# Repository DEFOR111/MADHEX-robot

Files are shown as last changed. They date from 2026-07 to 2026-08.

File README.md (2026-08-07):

# ***MADHEX — Open Source Hexapod Robot***
## 18 DOF · ESP32-S3 · Full custom PCB · CAD included
WhatsApp Image 2026-07-16 at 12 32 35 PM (1)

### ***A fully open-source hexapod project — PCB, CAD  included — for anyone who wants to build their own six-legged walking robot.***

***Features · PCB · CAD & Mechanics · Build Instructions · Gallery · Roadmap · Contributing***

-------------------------------------------------------------------------------------------------------------------------------------------------------------------------
## ***About:*** 
**MADHEX** is a fully open-source hexapod (six-legged) robot project. It includes a custom-designed power/control PCB, complete mechanical CAD files, and everything needed to build, wire, and bring your own hexapod to life — from soldering the board to your first steps in inverse kinematics.

**This repo is built for makers, robotics students, and hobbyists who want a real Hexapod .**

----------------------------------------------------------------------------------------------------------------------------------
## Features
	
* **18 DOF**	Full range of motion — walk, rotate in place, and climb
* **ESP32-S3-WROOM-1**	Onboard MCU handles inverse kinematics and gait control
* **Custom power PCB**	Compact board with dual buck converters, up to 600 W
* **BNO055 IMU**	Real-time orientation and stability feedback
* **32-channel PWM**	Room to expand with sensors, grippers, or accessories
* **All-terrain** capable	Stable gait tuned for uneven surfaces
* **Fully open**	PCB design, CAD, and build docs — all included

------------------------------------------------------------------------------------------------------------------------------------------------------------------
## PCB
PCB Top view

 ***The board is designed to be compact, efficient, and easy to assemble, while still driving 18 servos with headroom to spare.***

### Component	Spec
* Power stage	Dual buck converters, 40 A / up to 600 W combined — stable under peak servo load
* Servo power rails	2 independent lines (J5–J20 = rail A, J21–J36 = rail B) — 9 servos per rail for balanced current draw
* Current sensing	2× INA226 for real-time power monitoring
* PWM outputs	32 channels via 2× PCA9685
* MCU	ESP32-S3-WROOM-1 — inverse kinematics + gait control
* IMU	BNO055 — orientation, balance, stability
* Logic supply	AMS1117 3.3 V regulator
* I/O	USB-C, 2× SMD buttons

***Why it matters:*** **a small footprint board that reliably drives 32 PWM channels means more room in the chassis for batteries, sensors, or a gripper — without redesigning the electronics.**

Снимок экрана 2026-08-02 171105

### **DRC** - this PCB design includes only 2 warnings with 0 mistakes which means it is ready for manufactoring and these 2 warnings is just Kicad  and footprint problem of esp32-s3 footprint 

-------------------------------------------------------------------------------------------------------------------------------------------------------------------
## CAD 
WhatsApp Image 2026-07-16 at 12 32 35 PM (2)

| Spec | Value |
| :--- | :--- |
| **Size** | ~800 mm length × 300 mm height |
| **Servos** | DS3235 (high-torque, no secondary shaft) |
| **Shaft support** | Added bearings on each joint to compensate for the single-shaft servo design, reducing backlash and improving long-term stability |
| **Range of motion** | Mid-to-high performance angle range, tuned for smooth walking gait |

## building Instruction 

WhatsApp Image 2026-07-20 at 11 35 21 PM

* Print/order the chassis — CAD files in /cad
* Assemble the PCB — schematics and Gerbers in /pcb
* Wire the servos — respect the two power rails (9 servos per rail)

(FOR HACK CLUB: i have changed a bit of project in electronics to prevent it from braking after the submission )

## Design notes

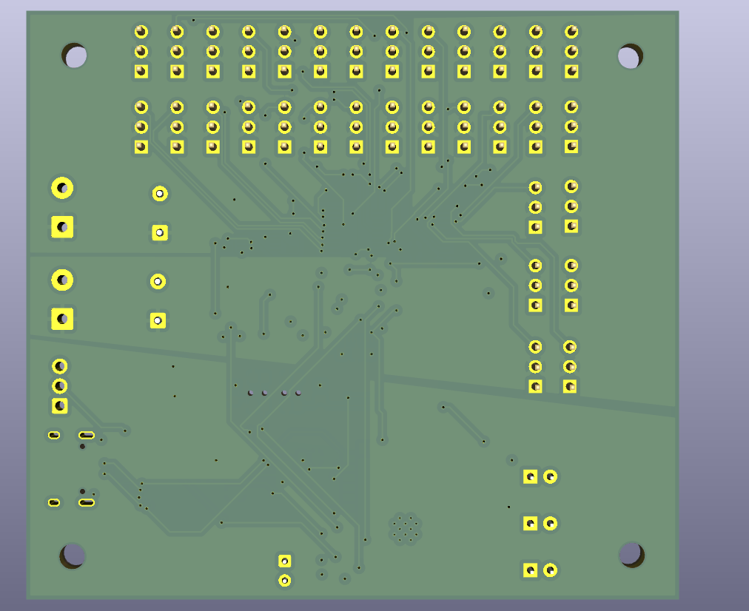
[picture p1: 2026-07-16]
Renders/PCB Bottom view.png

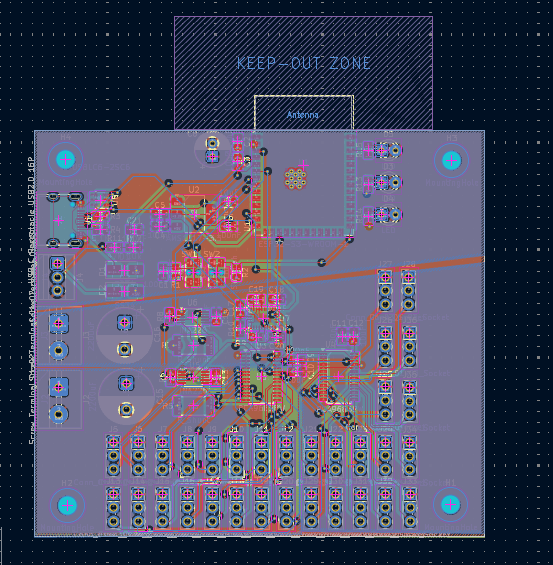
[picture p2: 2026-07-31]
Renders/4layer.png

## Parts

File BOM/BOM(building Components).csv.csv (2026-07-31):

name | quantity | price for quantity + delivery | link
DS3235 - 180 Servo | 18 | 246.78$ | https://aliexpress.ru/item/1005007575629790.html?sku_id=12000041358164109
servo horn | 2 | 11.13$ | https://aliexpress.ru/item/1005003027854823.html?sku_id=12000023318820499
3S Lipo battery 6000mAh | 1 | 45.34$ | https://aliexpress.ru/item/1005008702710375.html?sku_id=12000046311555698
300W 20A dc-dc step down buck converter | 2 | 9.14 | https://aliexpress.ru/item/1005004894829745.html?sku_id=12000030927228556
Esp32-s3-Wroom-1 module | 1 | 3.06$ | https://aliexpress.ru/item/1005010605134917.html?sku_id=12000052954553787
Usb-c 16 pin 0.8mm | 1 | 1.39$ | https://aliexpress.ru/item/1005007748645481.html?sku_id=12000042099025955
BNO055 IMU | 1 | 7.23$ | https://aliexpress.ru/item/1005008153313742.html?sku_id=12000044013847289
lm2596 step down buck converter | 1 | 0.77$ | https://aliexpress.ru/item/1005003780274326.html?sku_id=12000027142887130
Pca9685 | 1 | 4.36$ | https://aliexpress.ru/item/1005008013388973.html?sku_id=12000043251084556
diode s34 SMA | 1 | 1.5$ | https://aliexpress.ru/item/1005011924308998.html?sku_id=12000057043294917
LED lights | 1 | 0.89$ | https://aliexpress.ru/item/1005003483934428.html?sku_id=12000025994266348
INA226 | 2 | 1.39$ | https://aliexpress.ru/item/1005010486173276.html?sku_id=12000052565428459
16V2200uF Capacitor | pack | 1.1$ | https://aliexpress.ru/item/1005005698363806.html?sku_id=12000034044860759
16V100uF Capacitor | pack | 1.27$ | https://aliexpress.ru/item/1005005698363806.html?sku_id=12000034044860751
0805 smd 100nF Capacitor | pack | 1.05$ | https://aliexpress.ru/item/33010719216.html?sku_id=67141324253
0805 smd 10uF Capacitor |  | 1.19$ | https://aliexpress.ru/item/33010719216.html?sku_id=67141324254
Screw terminal 2.54mm 3PIN | 1 | 2.78$ | https://aliexpress.ru/item/1005007455322674.html?sku_id=12000040827977848
Screw terminal 5mm 2PIN | 2 | 2.25$ | https://aliexpress.ru/item/1005007455322674.html?sku_id=12000040827977861
male pin headers 1x40 | 1-2packs(we need 32 overall) | 2.10$ | https://aliexpress.ru/item/1005007067304088.html?sku_id=12000039296567404
0805 resistor 1k smd | pack | 1.07$ | https://aliexpress.ru/item/1005011924238866.html?sku_id=12000057033019725
0805 resistor 5.1k smd | pack | 1.07$ | https://aliexpress.ru/item/1005011924238866.html?sku_id=12000057033019742
0805 resistor 10k smd | pack | 1.07$ | https://aliexpress.ru/item/1005011924238866.html?sku_id=12000057033019749
0805 resistor 47k smd | pack | 1.07$ | https://aliexpress.ru/item/1005011924238866.html?sku_id=12000057033019765
R-Shunt 2512 3W-0.002 2mR | pack | 3.22$ | https://aliexpress.ru/item/1005012015238252.html?sku_id=12000057293682538
SMD 2Pin 3X4MM Tactile Tact Push Button Micro Switch | 2 | 1.5$ | https://aliexpress.ru/item/32752118872.html?sku_id=61896432967
ams1117 3.3v | 1 | 0.63$ | https://aliexpress.ru/item/1005008229056966.html?sku_id=12000048372042089
USBLC6-2SC6 SOT23-6 | 1 | 1.21$ | https://aliexpress.ru/item/1005009468432448.html?sku_id=12000049196393604
3D Printer Filament PETG 1.75mm 1kg/2.2lbs Plastic Filament Consumables PETG Material for 3D Printer | 1 | owned | https://aliexpress.ru/item/2042369676.html?sku_id=12000015581361162
688 series bearings | 2 | 3.68$ | https://aliexpress.ru/item/1005007514760760.html?sku_id=12000041090570973
M3 Inserts 3x5x4 | pack | 3.95$ | https://aliexpress.ru/item/1005009631947915.html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
M3 screws 12mm and 6mm | 2 packs of screws | 2.54$ | https://aliexpress.ru/item/1005002193355886.html?sku_id=12000019011281721
total price | 360.56$ + 16% VAT + delivery | 416.14$ for components

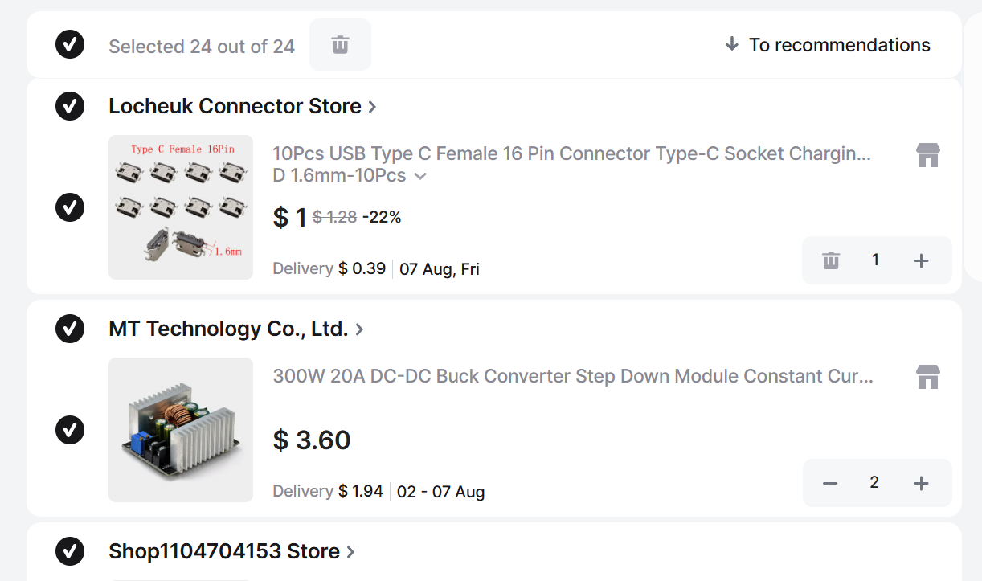
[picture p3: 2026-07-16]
BOM/cart aleiexpress 8.png

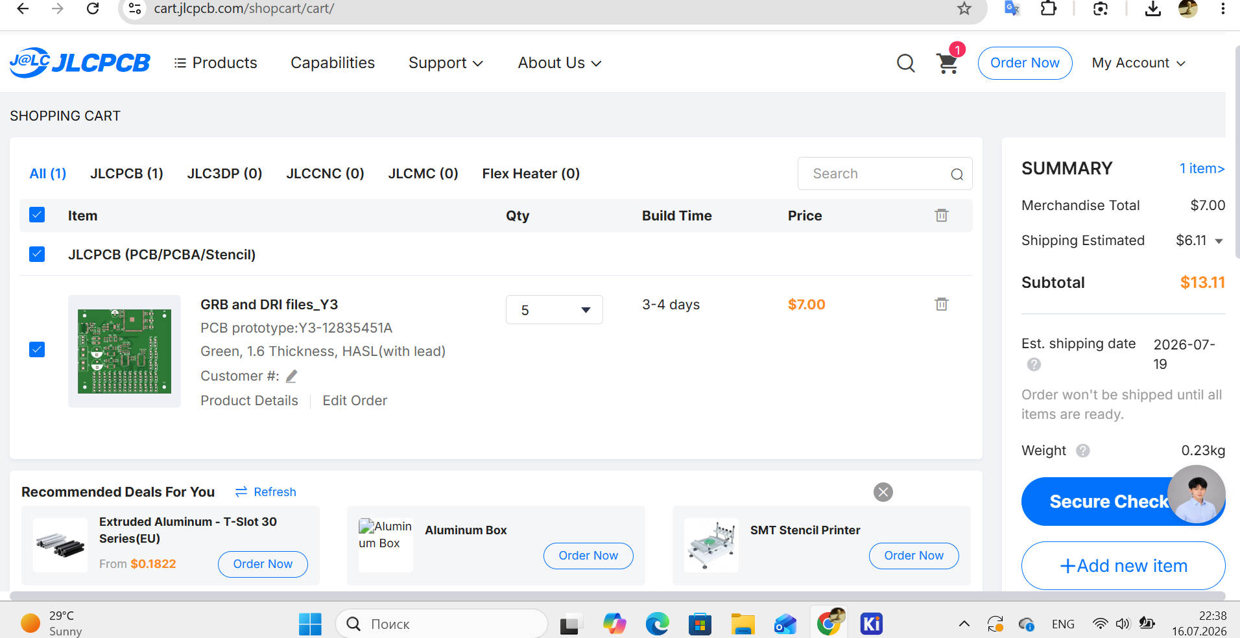
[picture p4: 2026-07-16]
BOM/JLCPCB cart hexapod.png

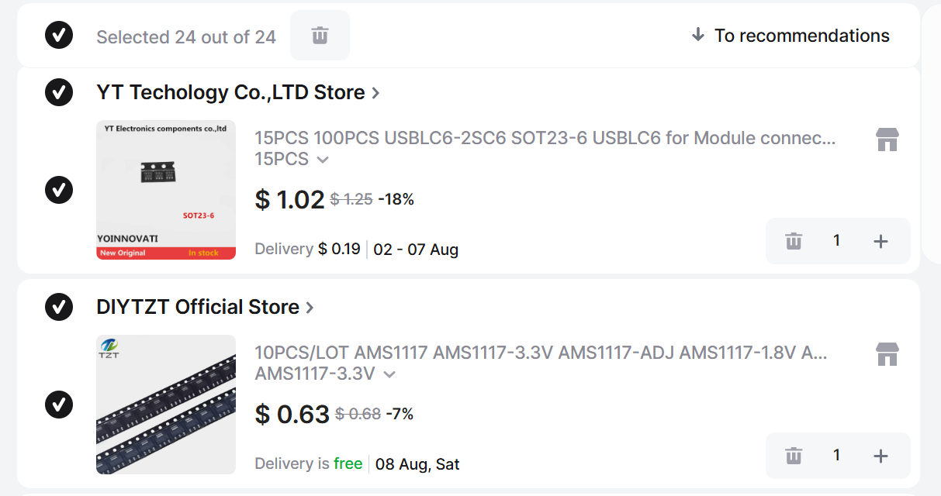
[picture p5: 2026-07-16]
BOM/cart aleiexpress 1.png

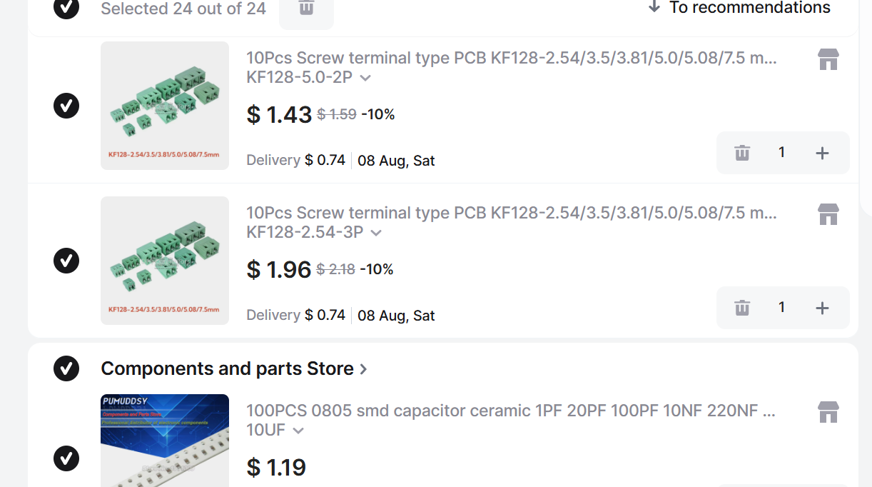
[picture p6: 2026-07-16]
BOM/cart aleiexpress 4.png

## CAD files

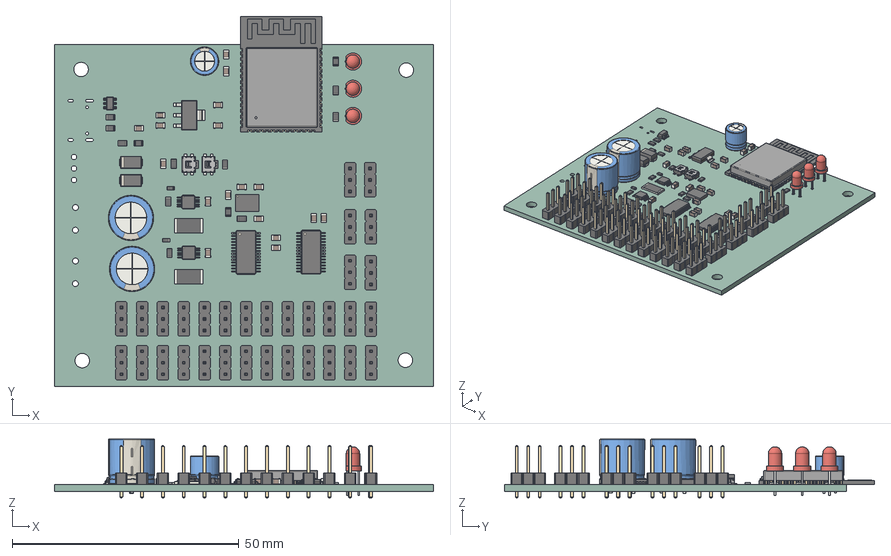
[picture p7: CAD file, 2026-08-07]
CAD/Hexapod PCB(CAD).step
83.6 x 81.6 x 13.0 mm
PinHeader_1x03_P254mm_Vertical x 32
C_0805_2012Metric x 18
R_0805_2012Metric x 13
R_2512_6332Metric x 2
D_SMA x 2
LED_D3.0mm x 3
CP_Radial_D100mm_P500mm x 2
R_0603_1608Metric x 2
ESP32-S3-WROOM-1
SOT-223
CP_Radial_D63mm_P250mm
SW_SPST_EVQP7C x 2
TSSOP-10_3x3mm_P0.5mm x 2
LGA_28_52x38mm_P05mm
TSSOP-28_4.4x9.7mm_P0.65mm x 2
SOT-23-6
HexF20F_PCB

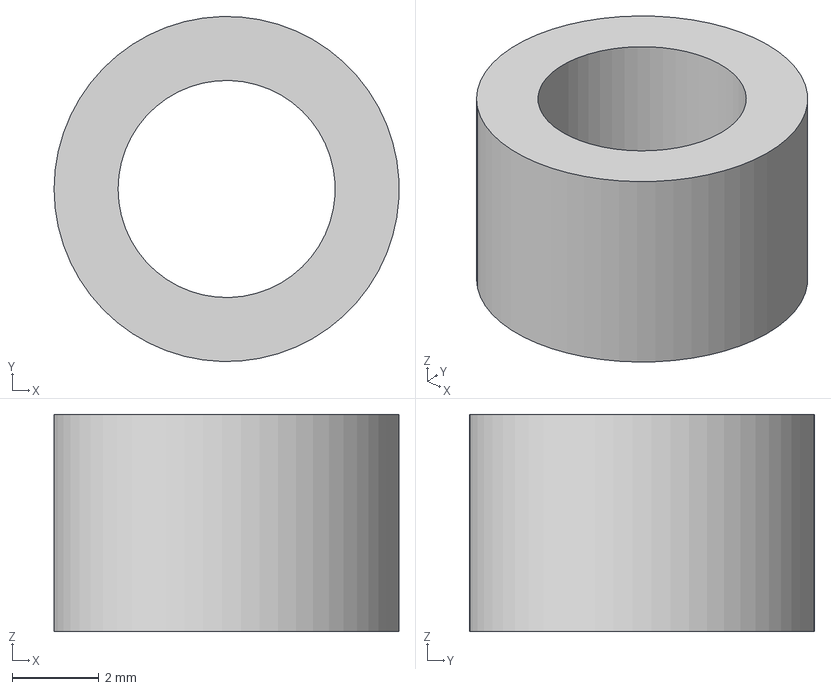
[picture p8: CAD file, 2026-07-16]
CAD/Step files/insert hold part.step
7.94 x 7.95 x 5.00 mm

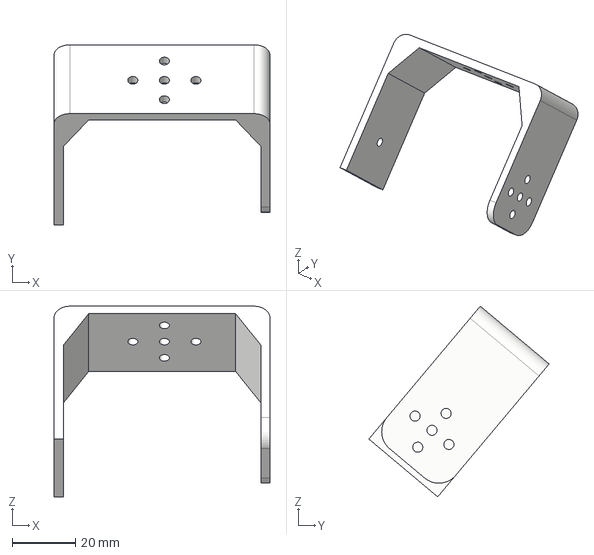
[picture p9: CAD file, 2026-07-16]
CAD/Step files/Femur mounting hub.step
68.5 x 57.2 x 60.5 mm

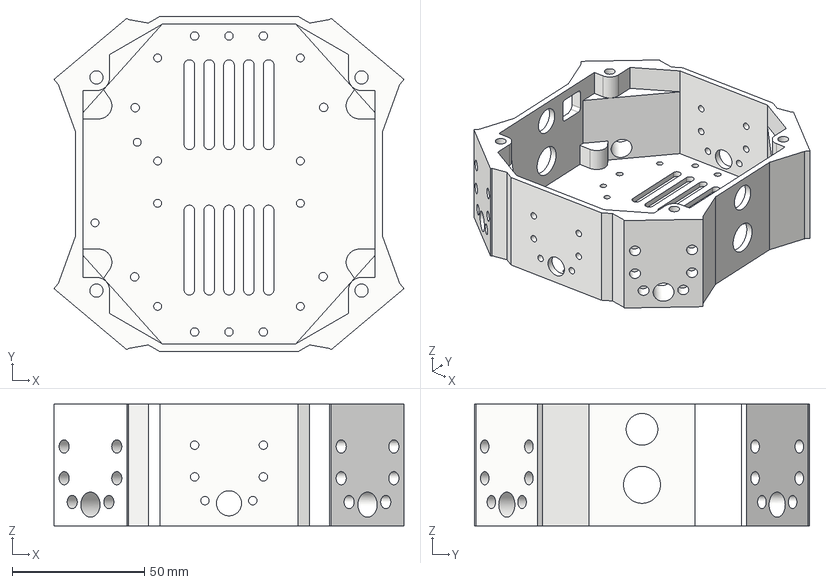
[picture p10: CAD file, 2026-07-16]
CAD/Step files/case.step
132.4 x 126.9 x 46.0 mm

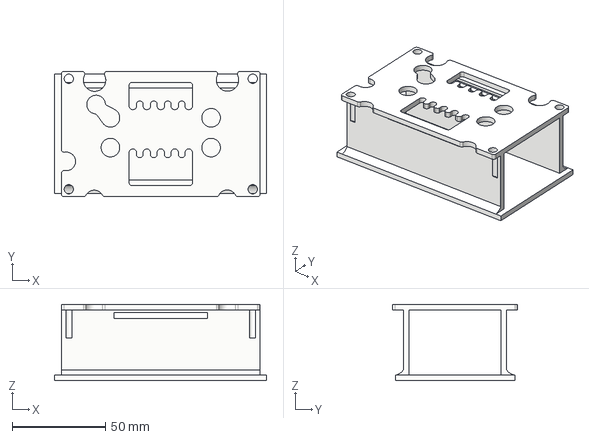
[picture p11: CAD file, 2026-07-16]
CAD/Step files/battery holder.step
113.7 x 67.2 x 41.0 mm

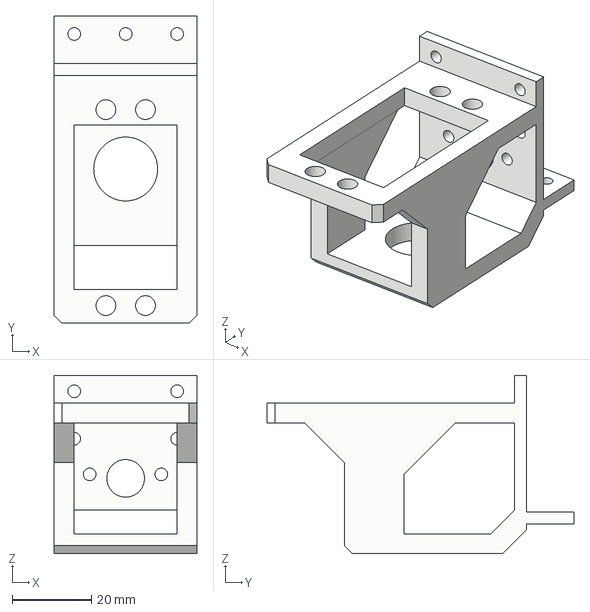
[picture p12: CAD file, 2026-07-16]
CAD/Step files/Coxa mounting hub.step
36.1 x 77.5 x 45.0 mm

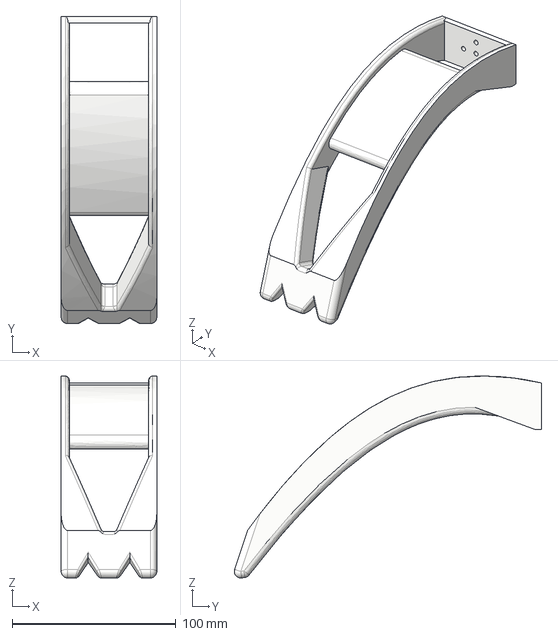
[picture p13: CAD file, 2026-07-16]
CAD/Step files/tibia Arm.step
58.5 x 188.0 x 123.5 mm

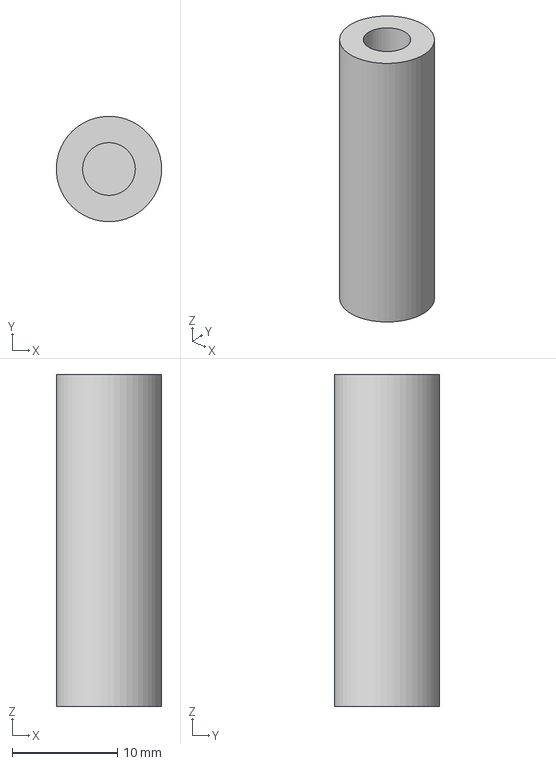
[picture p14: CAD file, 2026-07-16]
CAD/Step files/STANDOFF FRAME .step
9.99 x 10.00 x 31.5 mm

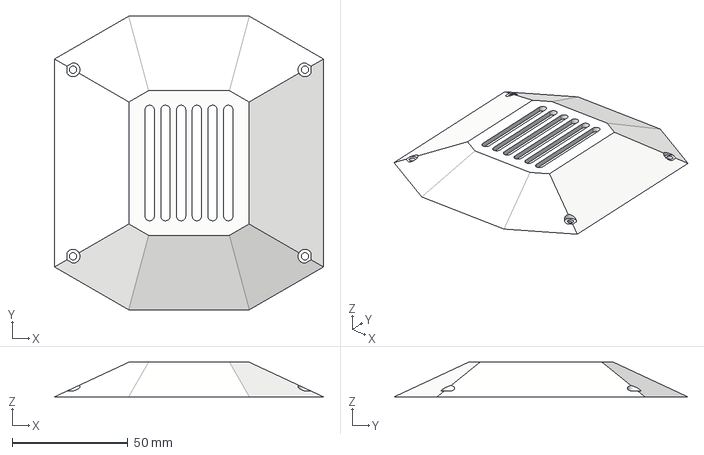
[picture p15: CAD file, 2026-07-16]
CAD/Step files/Central Case Cup.step
116.3 x 126.9 x 15.0 mm

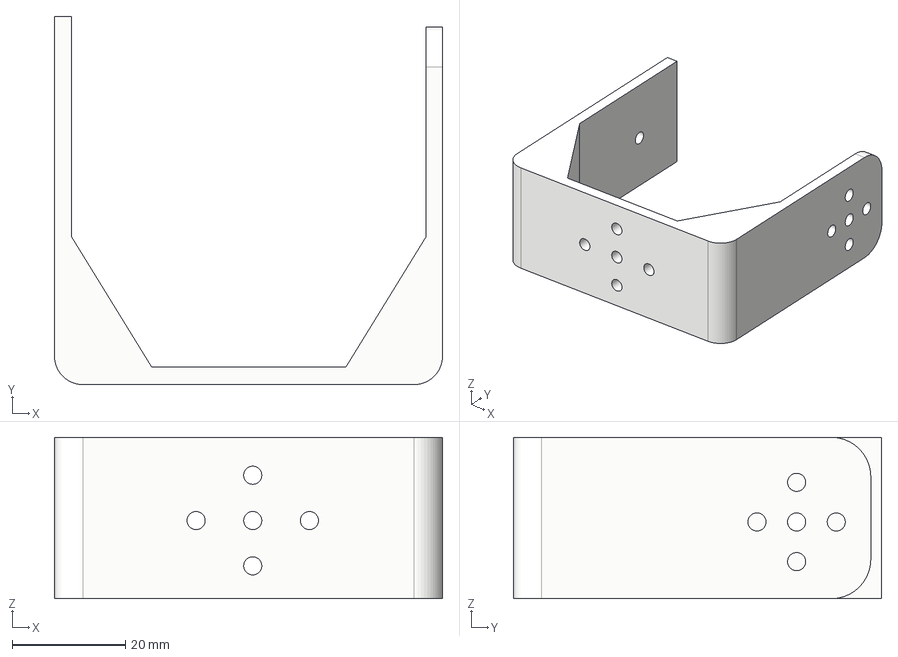
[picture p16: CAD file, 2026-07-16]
CAD/Step files/Tibia mounting hub.step
68.5 x 65.0 x 28.5 mm

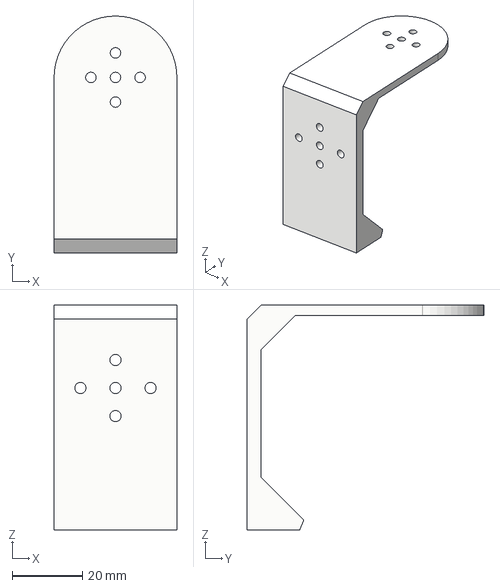
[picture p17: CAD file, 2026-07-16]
CAD/Step files/Coxa-Femur hub top.step
35.0 x 67.5 x 64.1 mm

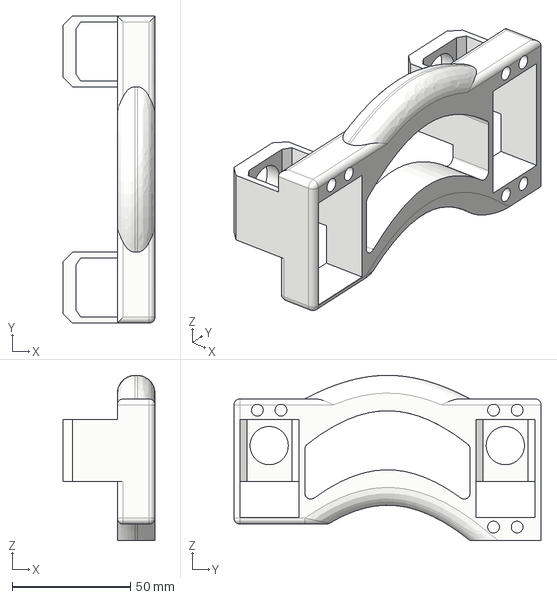
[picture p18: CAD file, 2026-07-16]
CAD/Step files/Femur arm.step
39.0 x 130.0 x 70.0 mm

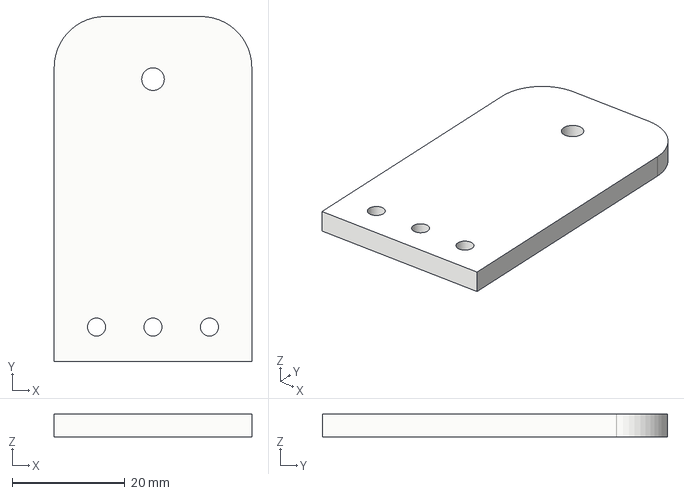
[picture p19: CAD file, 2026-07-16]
CAD/Step files/coxa-Femur hub bottom.step
35.0 x 61.1 x 4.00 mm

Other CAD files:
CAD/F3d files/Central Case Cup.f3d
CAD/F3d files/Coxa mounting hub.f3d
CAD/F3d files/Coxa-Femur hub top.f3d
CAD/F3d files/Femur arm.f3d
CAD/F3d files/Femur mounting hub.f3d
CAD/F3d files/STANDOFF FRAME.f3d
CAD/F3d files/Tibia mounting hub.f3d
CAD/F3d files/battery holder.f3d
CAD/F3d files/case.f3d
CAD/F3d files/coxa-Femur hub bottom.f3d
CAD/F3d files/insert hold part.f3d
CAD/F3d files/tibia Arm.f3d
CAD/STl files/Central+Case+Cup.stl
CAD/STl files/Coxa+mounting+hub.stl
CAD/STl files/Coxa-Femur+hub+top.stl
CAD/STl files/Femur+arm.stl
CAD/STl files/Femur+mounting+hub.stl
CAD/STl files/STANDOFF+FRAME.stl
CAD/STl files/Tibia+mounting+hub.stl
CAD/STl files/battery+holder.stl
CAD/STl files/case.stl
CAD/STl files/coxa-Femur++hub+bottom.stl

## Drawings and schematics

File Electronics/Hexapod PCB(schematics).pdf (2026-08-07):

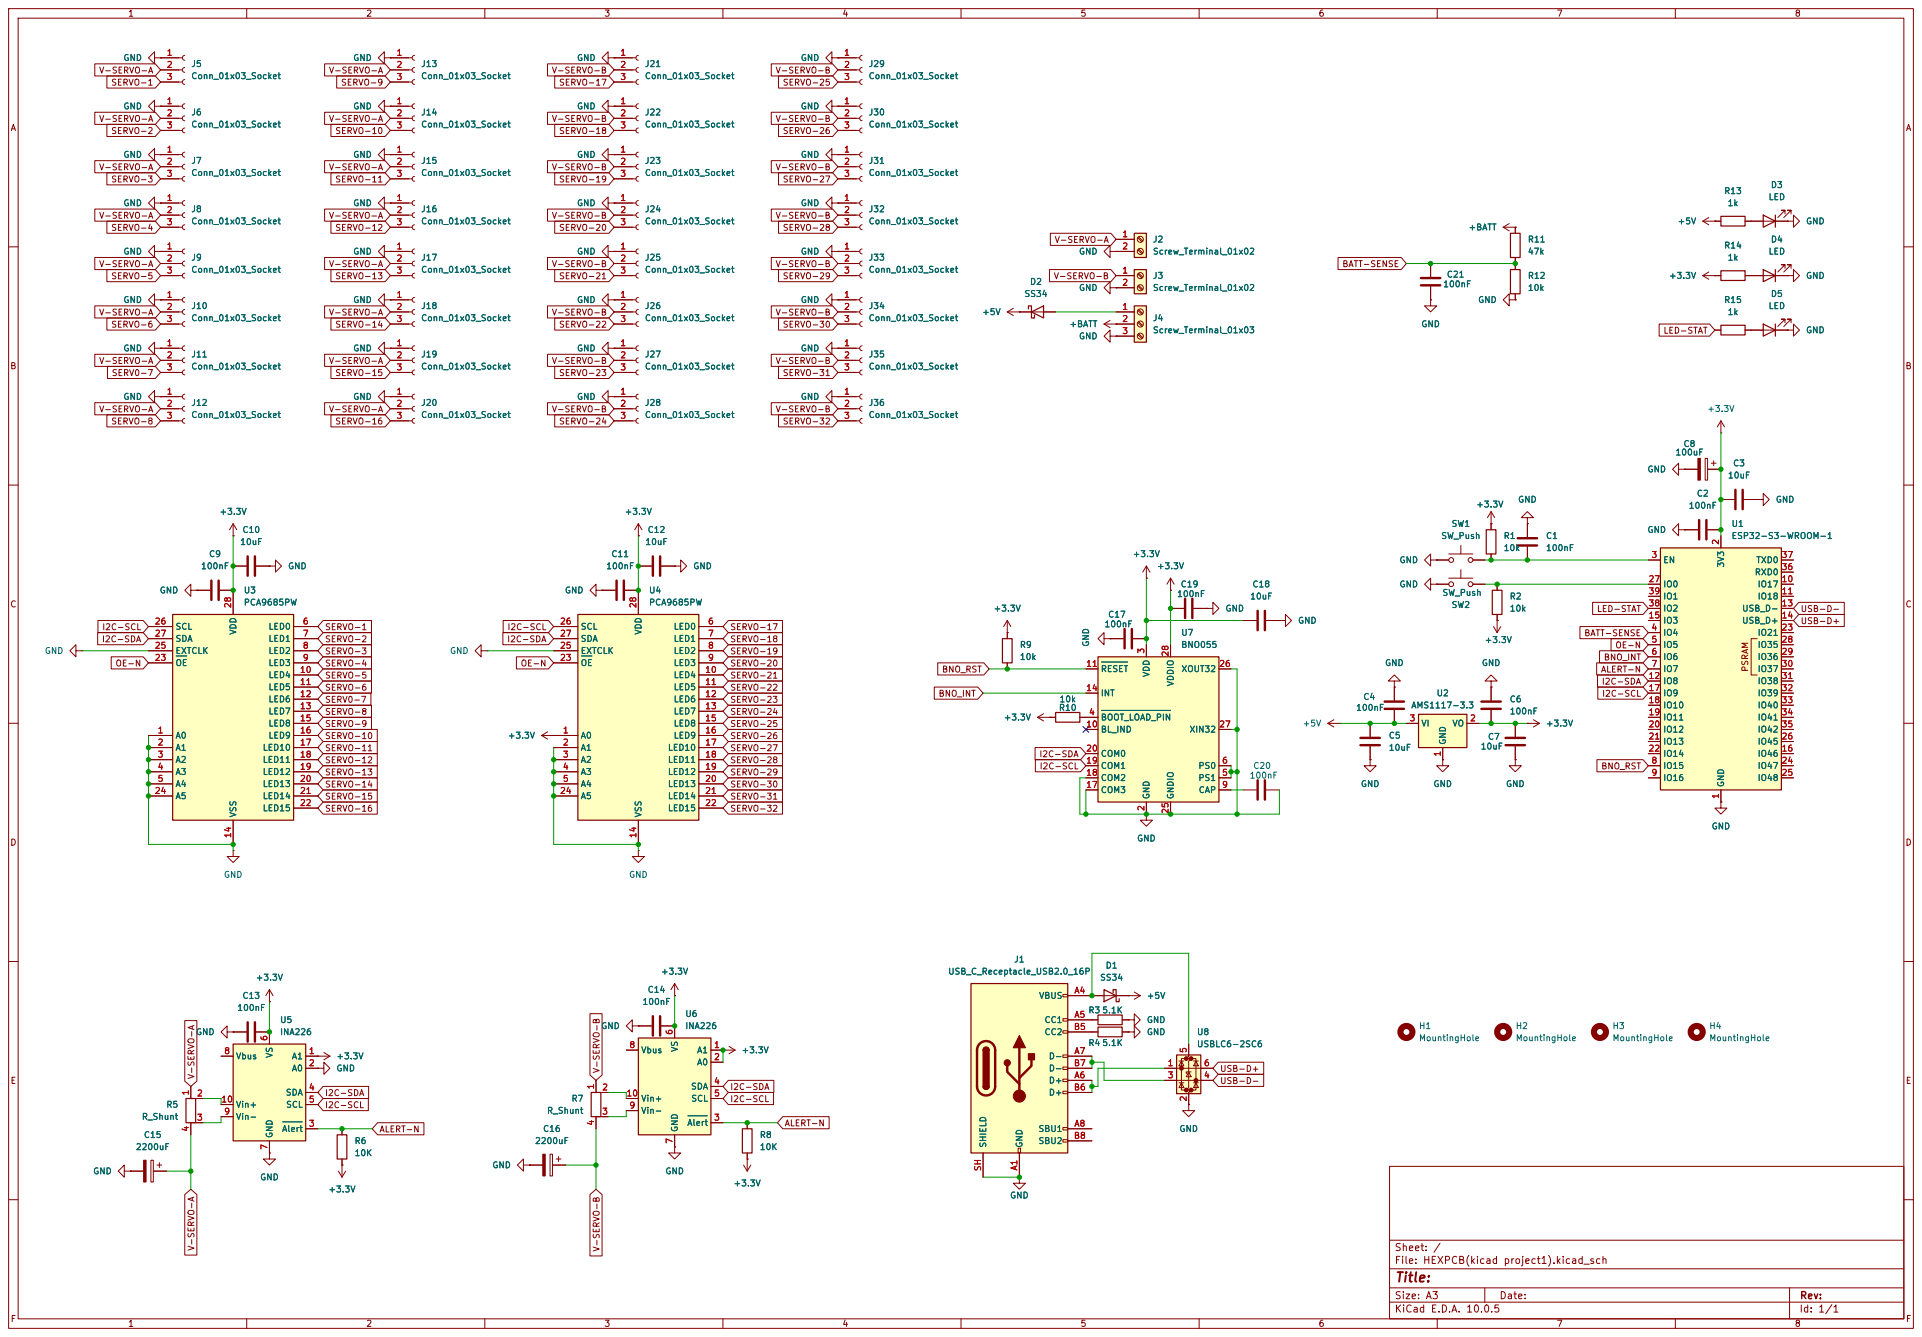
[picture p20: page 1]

Size: A3 | Rev: | F Date:
KiCad E.D.A. 10.0.5 | Id: 1/1

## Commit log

2026-07-16 Add files via upload
    added all f3d files 3d
    [Central Case Cup.f3d, Coxa mounting hub.f3d, Coxa-Femur hub top.f3d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]
2026-07-31 Rename Снимок экрана 2026-07-16 115600.png to CAD render1
2026-07-31 Rename Снимок экрана 2026-07-16 122454.png to cad render 2
2026-08-07 Rename HEXPCB(kicad project1).pdf to HEXPCB(schematics).pdf
